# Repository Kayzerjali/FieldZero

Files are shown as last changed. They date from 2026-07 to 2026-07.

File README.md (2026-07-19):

# FieldZero — Magnetic Field Cancellation for OPM MEG

System to reduce the residual magnetic field inside the QUBIC lab's mu-metal shielded enclosure, allowing the QuSpin QZFM sensors to zero and lock reliably.

See `docs/context.md` for full project context.

## Status

In development — lab access pending.

## Repository layout

```
docs/                 Project documentation (grows as work progresses)
data/
  raw/                Unmodified instrument output (write-once)
  processed/          Script outputs only — never hand-edit
Hardware/             KiCad — coil-driver PCB (see Hardware/Low_Current_Driver/)
  Common/             Shared symbol/footprint libraries
Software/             Python acquisition/analysis tooling
  src/fieldzero/      Python package
  scripts/
    characterisation/ Field measurement and analysis
    coil_cal/         Coil sensitivity calibration
    nulling/          Nulling procedure support
    figures/          All figure generation
  tests/
```

The Python setup and commands below are run from inside `Software/`.

## Setup

Python 3.11+. A venv is created per machine — **do not copy `.venv` between
machines**, it hardcodes absolute paths and platform-specific wheels. Recreate it
instead; it takes about a minute.

```powershell
py -m venv .venv
.venv\Scripts\activate
pip install -e ".[daq,dev]"
```

`[daq]` pulls in `nidaqmx`. Drop it on a machine with no card — `--mock` needs
nothing else. Drop `dev` if you are not running the tests. The NI-DAQmx driver
itself is a separate install from National Instruments and is not a pip package.

### Installing on a machine with no internet

Instrument PCs are often locked down. Build a wheelhouse **before** you go, on a
machine that does have network:

```powershell
.venv\Scripts\python.exe -m pip download -d wheels numpy scipy fastapi "uvicorn[standard]" nidaqmx
```

Copy `wheels/` across with the repo, then on the lab machine:

```powershell
py -m venv .venv
.venv\Scripts\activate
pip install --no-index --find-links wheels -e ".[daq]"
```

The front end needs no network either — uPlot is vendored into
`src/fieldzero/viewer/static/vendor/` rather than loaded from a CDN.

## Live viewer

```bash
python -m fieldzero.viewer            # against the NI-DAQ
python -m fieldzero.viewer --mock     # no hardware required
```

Opens a browser at `http://127.0.0.1:8000`. Split any pane left/right or
top/bottom and choose what goes in it: time domain, frequency domain (amplitude
or ASD), or phase (any channel against any other, with Pearson r and fitted
slope). The stats table below the panes gives per-channel mean and standard
deviation, and flags any channel sitting at the input rail.

Layouts persist across reloads and can be saved to / loaded from JSON.

Run `scripts/characterisation/verify_acquisition.py [--mock]` on arrival at the
lab to confirm the DAQ is reading every channel before starting a measurement.

The viewer binds to loopback, so a Windows firewall prompt on first run can be
declined. Use `--host 0.0.0.0` to watch from a laptop while the DAQ machine sits
in the shielded room — that one does need the firewall exception.

## Fallback scope

A plain matplotlib window. No server, no browser, no socket — a timer reads the
ring buffer in-process, so there is nothing between acquisition and the screen
that can stall, congest or time out. Use it if the browser viewer feels sluggish
on a given machine, or when you just want a scope up in one command.

It runs the same reducers as the browser viewer, so the DSP is identical: the
same windowing, the same ASD scaling, the same volts-based rail check, the same
correlation maths. Only the drawing differs.

### Running it

```bash
python -m fieldzero.scope                # against the NI-DAQ
python -m fieldzero.scope --mock         # no hardware required
```

With no `--pane`, you get one time-domain plot of all six channels. Close the
window to stop it.

### Choosing what to plot

`--pane` takes `KIND` or `KIND:CH,CH,...` and is **repeatable** — each one adds a
plot, stacked top to bottom in the order you give them.

| kind | channels | shows |
|---|---|---|
| `time` | any number (default: all six) | rolling time trace, newest sample at t=0 |
| `spectrum` | any number (default: all six) | amplitude spectral density, log axis |
| `phase` | **exactly two** | first against second, with a least-squares fit |

Channel names are `S1-X`, `S1-Y`, `S1-Z`, `S2-X`, `S2-Y`, `S2-Z` — the same names
the stats table uses. Get one wrong and it tells you the valid ones and exits.

```bash
# one time plot of two channels, and their spectrum underneath
python -m fieldzero.scope --pane time:S1-X,S2-X --pane spectrum:S1-X,S2-X

# is sensor 2 seeing the same field as sensor 1?
python -m fieldzero.scope --pane phase:S1-X,S2-X

# what is the residual on the Z axis, in raw volts, over 10 seconds?
python -m fieldzero.scope --pane time:S1-Z,S2-Z --units V --window 10
```

### The other flags

| flag | default | what it does |
|---|---|---|
| `--mock` | off | simulated source; no DAQ needed |
| `--window N` | `5` | seconds of history each pane shows |
| `--units pT\|V` | `pT` | display units. **Volts are ground truth** — the V/nT figure is unverified |
| `--fps N` | `10` | redraw rate. Drop it to `5` on a slow machine |
| `--sample-rate N` | `1000` | samples/second per channel. Startup only |

### Reading the window

The red or grey strip along the top is the readout, updated twice a second:

- Normally it lists every channel's mean ± standard deviation in the chosen units.
- If **any channel is at the input rail** it turns red and says so, and it says
  nothing else. That warning takes priority because a clipped channel still
  reports a mean that looks like a perfectly reasonable field value. When you see
  it, the true field on that channel is larger than ±5 V can represent, and every
  number from it is fiction.

A phase pane also prints its Pearson *r* and fitted slope into that strip: *r*
near 1 means both channels are seeing the same field, and the slope is the gain
ratio between them.

### What you give up

Panes are fixed at launch. There is no clicking, no splitting, no changing
channels while it runs — to change the layout, close it and relaunch with
different `--pane` flags. That is the trade for having nothing that can go wrong.

### If you edit `scope.py`

Rendering uses blitting, and has to. A full matplotlib redraw of three panes
costs ~120 ms (~8 fps), and the cost is the redraw itself — thinning the data does
not help. Blitting the traces over a cached background costs ~20 ms instead. Two
consequences are load-bearing:

- **A pane's axes contain traces and nothing else.** Rasterising text costs more
  per frame than every trace in every pane put together (~27 ms vs ~22 ms), which
  is why all text lives in the status strip — it has its own bbox, so it can be
  redrawn at 2 Hz independently — and why legends and titles sit *above* the axes,
  outside the blitted region, where they survive in the cached background for free.
- **Axis limits use hysteresis.** They only move when the data leaves them, because
  a rescale forces a full redraw. Rescaling every frame would throw away
  everything blitting buys. `test_scope.py` asserts steady state needs none.

## Acquisition notes

Sample rate is a **startup** parameter (`--sample-rate`, default 1000 Hz), not a
runtime one: changing it means rebuilding the DAQ task, and doing that mid-run is
what made the previous project's axis switching unreliable. The task is opened
once over all six channels and never reconfigured; selecting an axis is purely a
display concern.

Acquisition yields **volts**. The V/nT conversion is applied at display time
(see below) — so saturation is detected against the known input range rather
than an unverified sensitivity figure.

## Hardware

| Item | Status |
|---|---|
| QuSpin QZFM sensors × 2 | In lab — gen TBD |
| Cancellation coils | Not yet installed |
| Current source | TBD |
| NI-DAQ (Dev1, ai0–ai5) | In lab — model TBD, confirm in NI MAX |

Three acquisition settings in `src/fieldzero/config.py` need confirming against
the actual card. MEG_DSP never set them, so it silently ran on the `nidaqmx`
defaults:

| Setting | Value | Why it matters |
|---|---|---|
| `voltage_range` | ±5 V | Where a channel clips. This is the `nidaqmx` default, never a decision. At the inherited 2.7 V/nT that is a clip at ~1.85 nT — and the residual field is believed to be nT-scale, so channels may already be railing. |
| `terminal_config` | RSE | RSE vs differential materially changes the noise floor. |
| `sensitivity_v_per_nT` | 2.7 | **Unverified** — inherited from MEG_DSP, and the QZFM generation is still unconfirmed. Volts are ground truth until this is checked against the sensor label. |

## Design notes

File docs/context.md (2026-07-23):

# FieldZero — Project Context

## The problem

The QUBIC MEG lab uses two QuSpin QZFM zero-field magnetometers inside a mu-metal shielded enclosure. The QuSpin has an internal field-zeroing loop but it has a limited capture range — it can only null the field if the residual field is already weak enough. The residual field inside the enclosure is strong enough that the internal zeroing either takes excessively long (~10 minutes) or fails entirely.

The lab previously spent time trying to fix this in software before realising the root cause was hardware: the residual field simply exceeds what the QuSpin internal coils can handle.

## The goal

Reduce the residual magnetic field inside the enclosure enough that the QuSpin internal zeroing acquires quickly and reliably. Once it locks, it handles the rest. This is a coarse acquisition problem, not a cancellation problem — the DC/quasi-static saturation-escape criterion is the core success bar.

**Architecture (scope shift from static trim)**: target moved from manual potentiometer set-and-forget to an active closed-loop PID cancellation system, per supervisor request. Not a one-time manual null.

**Success criterion**: both QuSpin sensors zero and lock in under ~2 minutes without intervention. This is not a strict requirement — it is a guide.

**Deliverable**: a system simple enough that any lab member can operate it following a procedure, without the original engineer present.

## Prior art

Holmes et al. 2023 (matrix coil active shielding for ambulatory MEG) is the direct predecessor: 48 unit coils on two planes, optical tracking for pose, spherical-harmonic projection (3 uniform + 5 gradient) via pseudo-inverse chained to a coil forward-model inverse, proportional feedback (Kp=0.4, 40 Hz, 25 ms latency), static shielding factor ~13.7×, moving ~5.2×. Their complexity (tracking + 48-coil inversion) solves a moving target over a whole-head volume — a problem we don't have with a small static 2-sensor enclosure. HFC (Tierney/Mellor) is the software-only version of the same harmonic projection; it's the lineage from the earlier 2-sensor common/differential PCA work → HFC → matrix coil.

## Field model and coil drive (worked through by hand, not yet bench-verified)

- Field over the region: B(r) = b₀ + G·(r−r₀) — uniform vector + gradient tensor. Needed because coils act over a region but we only measure at 2 points.
- Forward model y = H·b₀ (H from sensor geometry, not data), solved as b₀ = H⁺y. For two co-oriented triaxial sensors this collapses to: uniform = average of the two readings, gradient = difference / separation — the physics-derived version of the existing PCA common/differential split.
- **Observability limit**: 2 sensors separated along z can only observe ∂B/∂z (the z-column of G). Other gradient components are structurally invisible with this geometry.
- **Coil drive decomposition**: a biplanar pair has two natural modes — common mode (both coils same direction) → uniform field, differential mode (opposite) → gradient. This is a square, invertible 2×2 system: 2 observables (uniform Bz, ∂Bz/∂z), 2 knobs (common current, differential current). Physical currents I_T, I_B solved via M⁻¹ where M = [[p,q],[q,p]] (p,q = near/far coupling per amp, from Biot–Savart or bench).
- Currently z-axis only — a full uniform-vector cancellation needs 3 orthogonal coil pairs (Bx, By, Bz).

## Control architecture (settled)

The single-shot M⁻¹ solve applied every timeslice is itself a P-controller with Kp=1, but assumes a perfect forward model and static disturbance (both false — coil calibration is rough, field drifts). Fix: wrap the inversion in feedback — M⁻¹ gets close fast (feedforward), an integral term grinds to true zero (absorbs model error + drift). Practical form: PI, integral-dominant, one loop per drive mode (common-mode current, differential-mode current). D-term omitted — amplifies OPM noise, unnecessary for DC/quasi-static. Sign per axis must be verified on the bench (wrong sign → runaway).

Two nested loops in series: external coil loop = coarse acquisition into the QuSpin's ±few-nT capture range; QuSpin's internal null = fine trim. Bootstrapping: QuSpins are saturated on day 1, so the fluxgate does initial characterization until they come into range, then the OPMs become the loop sensor.

## Sensor data path (settled 2026-07-24)

How QZFM readings reach the coil driver. Each QZFM electronics module has **two independent outputs to the PC**: (1) **analog** — BNC per axis, ±5 V rail-to-rail, gain-selectable (2.7 V/nT default, 0.9 V/nT low, 8.1 V/nT high), read by the lab's NI DAQ (NI-9205, QuSpin's recommended unit); (2) **USB digital serial** — an FT232RL virtual COM port (115200 8N1) used by the QuSpin UI for calibration/zeroing/gain, which also streams 24-bit field values on the `Print ON` command (`(raw − 8388608) × 0.01 = pT`).

**Chosen path: PC-in-the-loop ("A1").** fields → NI-9205 (or QZFM USB serial) → PC (Python PID) → USB → Nano R4 → DAC8814 (SPI) → coils. The **MCU is a DAC bridge**, not the controller: it translates USB current commands to SPI DAC writes, holds the last-commanded current, and drops to safe-state (zero-current code) if the PC stops. Rationale: the loop is DC/quasi-static (<~few Hz), so the PC round-trip (~5–30 ms) is irrelevant — Holmes ran a harder moving-target loop at 40 Hz / 25 ms; **v010 already implements A1 with no board change**; and a PC is required in the room for the QuSpin UI regardless, so full MCU autonomy buys little (see [autonomous mode](#improvements--extensions-deferred) in Extensions).

**Ruled out: "NI DAQ → MCU directly."** An NI USB/cDAQ device is a USB peripheral requiring the NI-DAQmx driver stack on a host PC; the Nano R4 cannot host it. There is no DAQ→Arduino path.

**Capture-range caveat:** the QZFM analog output clips at ±1.85 nT (default gain) / ±5.5 nT (low gain), so the OPMs are only usable as the loop sensor once the field is already within range — the fluxgate must carry the bootstrap phase whichever routing is used.

## Electronics (settled)

Architecture: MCU → DAC → voltage-controlled current source (VCCS) per coil. Rejected DAC + series resistor (current = V/R_total drifts with coil copper temperature). VCCS uses a precision sense resistor inside the op-amp feedback loop so current is pinned at V_control/R_sense regardless of coil resistance.

Howland vs. series-sense is current-dependent, not a blanket call. Mrozowski et al. 2022 (Vernier Current Driver) show Howland current pumps degrade above ~50 mA — resistor self-heating unbalances the bridge, CMRR drops, and the drive stage's own heat couples into the control loop. Below that, their Howland-based LCD (DAC8814 + LTC6655 ref + OPA2210 pump) measures 14.6–15.1 ppb/√Hz, beating their series-sense HCD (16.5 ppb/√Hz at 250 mA). Our coil current for a ±10 nT trim field is expected well under 50 mA, so **adopting the LCD topology wholesale** (Howland pump, same op-amp/DAC/reference) rather than series-sense — revisit only if the coil transfer function (still unmeasured) demands more current than that.

Spec priority, in order:
1. Low current noise in-band — cheap to mitigate since the loop is <~few Hz, so filter hard / use a slow op-amp.
2. Short-term stability / low offset drift — use a chopper/auto-zero op-amp (offset appears as V_os/R_sense current error, kills it at DC).
3. Bipolar source-and-sink (currents go negative and flip sign — needs bipolar supply, no PWM/H-bridge switching noise).
4. Absolute accuracy matters least (feedback absorbs it).

R_sense: low-tempco foil/metal-film, sized so V_sense ≫ op-amp offset. DAC: ≥16-bit floor, resolution set by (total field span / capture range); possibly coarse+fine split.

## PCB (settled — as-built for first prototype, rev 0.1 / "v010")

The first prototype is board **rev 0.1** (schematic title-block `rev "0.1"`), referred to as **"v010"**; the next respin is **v011**. Working KiCad project: `Hardware/Low_Current_Driver/` — a duplicate of the Strathclyde Vernier LCD reference design, kept alongside its own copy of `Common/` since the lib tables use `${KIPRJMOD}/../Common/...` relative paths. The stray upstream clone under `docs/Vernier-Current-Driver/` is left untouched as reference — `Hardware/Low_Current_Driver/` is the only one that should be edited.

**Hierarchy (after the multichannel refactor):** root → `DAC` (→ `DAC_OPA` ×2, the A/B DAC buffers) · `MCU` · `Channel_Outputs` ×2 (`Coil_Drive_A`, `Coil_Drive_B`). The two coil drive channels are native KiCad multichannel instances of one `Channel_Outputs` sheet (z-axis common/differential — matches current single-axis scope). The reference design's `Power`, `Battery_Management`, and `Mounting_Holes` sheets were **removed** — see power entry below.

**Board specifics (settled, schematic-verified):**
- **MCU: Arduino Nano R4** (`A1`, replaces the reference design's ESP32-S3). The digital 5 V rail (`5VD`) is sourced from the Nano's own 5 V pin, not an on-board regulator. The ESP32-S3 symbol/footprint/STEP leftovers have been deleted and its `sym-lib-table` entry removed.
- **Power entry: external raw ±9 V through a 4-position Phoenix screw terminal** (`J3`, MKDS-1,5/4-5,08, MPN 1729144) carrying `+9V` / `−9V` / `GND` / `GNDA`, switched by a panel DPST switch (`SW1`, E-Switch RA83231100). The design source is **series 9 V batteries** (center-tapped for ground — the Vernier low-noise heritage; 9 V cells + snap leads are on the DigiKey list); a bench supply can substitute for characterization. **No on-board regulation or battery-management stage** — the reference design's ±12 V→±9 V LDOs (U4/U5/U6) and reverse-polarity front end are gone; raw ±9 V feeds the rails directly (down from the reference's ±12 V, adequate for the op-amp swing needed).
- **Coil connections: Molex Micro-Fit inline connectors** (`J1`, `J2`) — enamel coil wire spliced to a silicone-wire pigtail, crimped into a Micro-Fit, mated to a matching PCB-side connector.
- **Schematic ERC:** the two active drive channels (DAC A/B → buffers → coils) are clean. Two residual ERC errors remain on the DAC8814's **unused** C/D current outputs (`Iout_C`/`Iout_D` tied together and parked with a `PWR_FLAG`) — schematic-annotation only, no functional or copper impact; left as-is for the prototype.

**First-prototype scope cut (revisit before any lab-deployed build)**: the first board deliberately trades robustness for speed to get a characterization prototype on the bench. On-board power conditioning is omitted wholesale: no regulation (raw ±9 V comes straight from the battery pack), no reverse-polarity protection (MOSFET pair / polyfuses / TVS), no power-good LEDs or front-panel LED connector. A hard DPST switch (`SW1`) is the only power control — no soft on/off. Net effect: the board depends on a correctly-wired ±9 V source (battery pack or bench supply) and is unprotected against a reversed or over-voltage input. Acceptable for the bench-test/characterization build only; the project's own "operable by any lab member without the engineer present" deliverable goal implies regulation, protection, and idiot-proof power entry belong in whatever board actually ships to the lab.

## Protection — coil/op-amp side (settled by analysis)

Distinct from the reverse-polarity/idiot-proofing cuts above: the inductive-transient protection on the op-amp→coil side was analyzed on physics grounds and found genuinely unnecessary at this energy level — not a deadline compromise.

- **Stored coil energy is negligible.** E = ½LI² = ½(4 µH)(10 mA)² = **200 pJ** — seven orders of magnitude below a barely-perceptible ESD event.
- **SW1-off / brownout:** the coil sits in series with the sense resistor, so decay τ = L/R ≈ 4 µH / 1 kΩ ≈ 4 ns. The coil fully de-energizes ~a million times faster than the ±9 V rails can sag; the ~10 mA is far below any ESD-diode / latch-up threshold. **No op-amp output→rail clamp needed.**
- **Hot-unplug:** V_peak = I·√(L/C) into stray capacitance is only ~2–6 V — won't arc a connector and is trivially inside op-amp tolerance. A board-side clamp couldn't protect the coil anyway (it leaves on the far side of the break). **No coil-side TVS needed.**
- **Safe power-down is a firmware sequence, not hardware:** command all DAC channels to zero-current code (mid-scale for the bipolar output), assert `LDAC` so the op-amp ramps coil current to zero under closed-loop rail-bounded control, wait a few τ (ms is ample), *then* cut power. Coil energy is already zero before control is lost.
- **The one conditional item: MCU `D1` (VIN backfeed diode).** Only justified if the actual Nano R4 backfeeds its VIN pin when USB-powered with the ±9 V supply off. Decide by one measurement — power from USB only, bench supply off, read VIN: ~0 V → no protection diode needed at all; ~4–5 V → keep a series Schottky on VIN only. (The old `D2` 5 V-bridge diode was DNP — never populated, a no-op.)

## Fabrication — first prototype (settled 2026-07-23)

- **Board:** 4-layer, 127.75 × 53.0 mm, stackup F.Cu / GND / PWR / B.Cu. Ordered as a **bare PCB** (hand-assembled from the DigiKey BOM, not JLC PCBA).
- **Fab package:** `Hardware/Low_Current_Driver/fab1.zip` — gerbers + PTH/NPTH drills, regenerated 2026-07-23 08:16, byte-matches the current `.kicad_pcb`.
- **JLC quote:** $29.20 = $4.20 board + **$25 engineering (NRE) fee**, triggered by 4 layers **and** the >100 mm long edge (both push the order out of JLC's free-prototype tier). Not worth redesigning around — the GND/PWR planes are worth more than the fee.
- **DRC (KiCad 10.0.4, current board):** 0 errors, 0 unconnected, schematic parity clean; 1 cosmetic warning only (silk clipped by mask on an `HCP` test-point ref) — JLC auto-clips, non-blocking.
- **BOM / DigiKey:** MPN + DigiKey link live on each schematic symbol (no external BOM file); the curated purchase list is the DigiKey mylist **"FieldZero"** (7UCPWN2VGF), which also carries the 9 V batteries + snap leads (power source, not schematic symbols). All 15 schematic MPNs re-verified **Active** on DigiKey 2026-07-23, every one in stock except **J3 (Phoenix 1729144), Active-but-0-stock — deliberately off the order because the engineer has it at the UQ lab.** Parts ≈ $110/board at qty 1, dominated by DAC8814 $46.61, 4× OPA2210 $25.48, LTC6655 $14.63, Nano R4 $13.30.
- **Known metadata drift (harmless):** 100 nF caps carry Kemet `C0603C104K5RACTU` on the schematic vs Samsung `CL10B104KB8NNNC` on the PCB footprints — the orderable BOM exports from the schematic (Kemet). Test-point reference designators also differ between schematic (`TP15`…) and PCB (net-name labels). Neither affects the copper or the parts order.

## What is known

- Residual field estimated in the nT range
- Enclosure is mu-metal, sized to comfortably fit a styrofoam head with sensors mounted
- QuSpin software and NI-DAQ acquisition (Dev1, ai0–ai5, 2 sensors × 3 axes) already working from prior lab work
- The mu-metal provides passive attenuation but leaves a residual that exceeds the QuSpin capture range

## What is not yet known

- QuSpin gen — check hardware label when in lab (determines capture range and sensitivity spec)
- Exact residual field magnitude and which axes are worst — must be measured
- QuSpin internal capture range — need datasheet for confirmed gen
- Whether existing cancellation coils are installed or enclosure is bare
- Whether gradient control is needed at all: uniform-only cancellation leaves each sensor at ±(gradient×a); if that residual is below QuSpin capture range (~few nT), differential control can be skipped. Sensors are close together so uniform-only likely suffices, but the fluxgate campaign must measure the actual gradient across the baseline before deciding.
- Actual QZFM triaxial output and sensor separation vector — fixes H and the true loop count
- Coil geometry — determines whether the op-amp drives the coil directly (tens of mA, simple) or needs a pass transistor / power op-amp (amps, op-amp becomes the controller with R_sense staying in loop). Working estimate (≈4 µH inductance, ≤10 mA full-scale for a ±10 nT trim) sits firmly in the direct-drive regime, so no pass transistor is planned — provisional until the coil transfer function is bench-measured.

## Improvements / Extensions (deferred)

Forward-looking work that is understood but deliberately **not** in v010. Consolidated here so a v011 respin has a single checklist. Each item is traceable to a decision or measurement gap above.

- **Autonomous mode (no PC in the control loop).** The chosen path is PC-in-the-loop (see [Sensor data path](#sensor-data-path-settled-2026-07-24)); autonomous mode moves the PID onto the MCU and reads the QZFM analog outputs directly, so the box cancels with the PC out of the loop (NI DAQ demoted to logging/characterization). Requires a v011 respin: a **6-channel bipolar analog front-end** (±5 V QZFM outputs → attenuate + offset + anti-alias into ADC range) feeding a **dedicated SPI ADC** (≥16-bit, e.g. ADS1256-class) rather than the Nano R4's 14-bit unipolar onboard ADC. Justified only if a standalone (PC-free) controller is wanted — the QuSpin UI already needs a PC in the room, so this is a feature, not a requirement. The ±1.85/±5.5 nT analog clip still applies: the fluxgate carries bootstrap regardless.
- **Power conditioning + protection** (the first-prototype scope cut, above). For any lab-deployed board: on-board regulation (reference design's ±12→±9 LDOs or equivalent), reverse-polarity protection (MOSFET pair / polyfuses / TVS), power-good LEDs + front-panel LED connector, and ideally soft on/off replacing the hard DPST switch. v010 depends on a correctly-wired ±9 V source and is unprotected against reversal/over-voltage — bench-only. The "operable by any lab member" deliverable implies these belong on the shipped board.
- **Full 3-axis uniform cancellation.** v010 is z-axis only (2 channels: common/differential Bz). A full uniform-vector null needs 3 orthogonal coil pairs (Bx, By, Bz). The native multichannel sheet structure makes replicating the drive channel cheap; the DAC8814 is quad (2 channels used, 2 spare — one more axis fits before a second DAC is needed). Real constraints are board area and coil connectors.
- **Gradient control — decide, then possibly drop.** Whether differential (gradient) drive is needed at all depends on the measured gradient across the sensor baseline. If uniform-only cancellation leaves each sensor below QuSpin capture range, differential drive can be dropped, halving channels per axis. Blocked on the fluxgate gradient measurement (see What is not yet known).
- **Drop the NI DAQ from the loop.** Read fields straight off the QZFM USB serial (`Print ON`, 24-bit) if the stream rate suffices for a few-Hz loop, removing the NI-9205 from the control path: QZFM USB → PC → MCU USB. Keep the DAQ only for characterization/logging. Confirm the serial stream rate in the lab before committing.
- **Higher coil current (pass transistor / power op-amp).** Direct-drive (≤10 mA, Howland pump) assumes the ≈4 µH / ±10 nT working estimate holds. If the bench-measured coil transfer function needs >~50 mA, Howland degrades (sense-resistor self-heating unbalances the bridge) — switch to series-sense and/or add a pass transistor with R_sense kept in the loop.
- **DAC coarse+fine split.** If the required resolution (total field span / capture range) exceeds a single 16-bit DAC's usable range, split into summed coarse+fine DACs. Not needed at current working numbers; revisit after the field magnitude is measured.
- **MCU VIN backfeed diode (D1).** Conditional item from the protection analysis: only if the Nano R4 backfeeds VIN when USB-powered with ±9 V off. One measurement decides (VIN under USB-only power: ~0 V → no diode; ~4–5 V → series Schottky on VIN). Cheap to add on a respin.

## Resources
- A working example or capturing data from the qzfms can be seen in the repo
"https://github.com/Kayzerjali/MEG_DSP.git".
- Vernier Current Driver (Strathclyde EQOP, Mrozowski & Chalmers) — open-source ultra-low-noise bipolar current source, reference design for the coil-driver electronics and PCB: https://github.com/Strathclyde-EQOP/Vernier-Current-Driver — paper: https://arxiv.org/abs/2207.10348

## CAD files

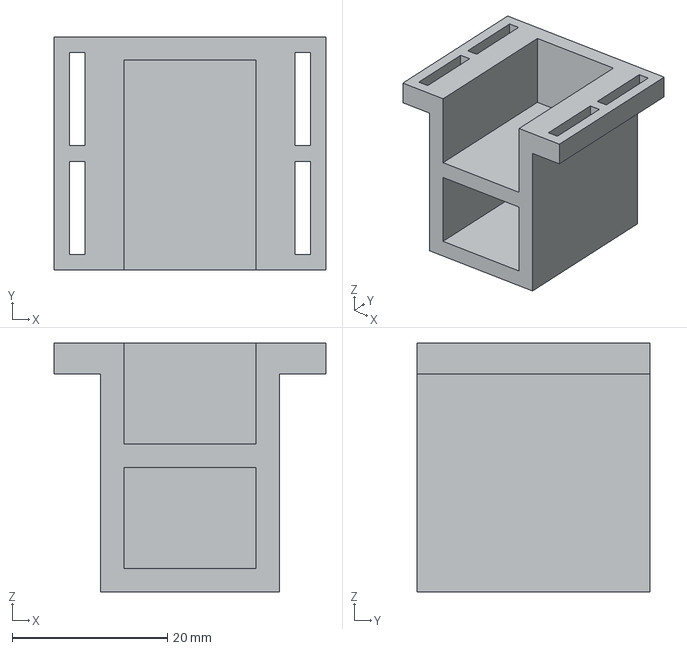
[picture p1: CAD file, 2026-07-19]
Hardware/cad/2sensor_holder_cap_hooks_pt.stp
35.0 x 30.0 x 32.0 mm

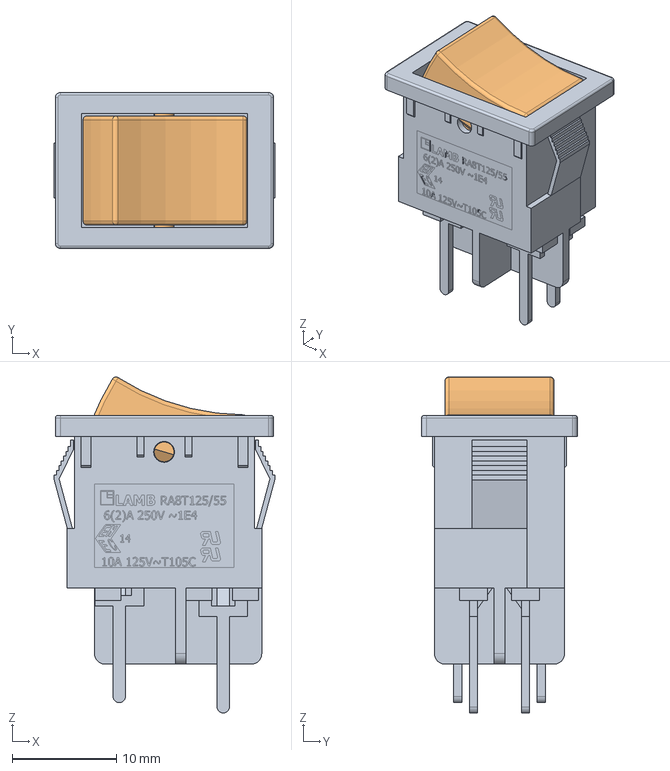
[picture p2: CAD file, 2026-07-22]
Hardware/Low_Current_Driver/3DModels/RA8323xx00 (1).stp
21.2 x 15.0 x 32.3 mm

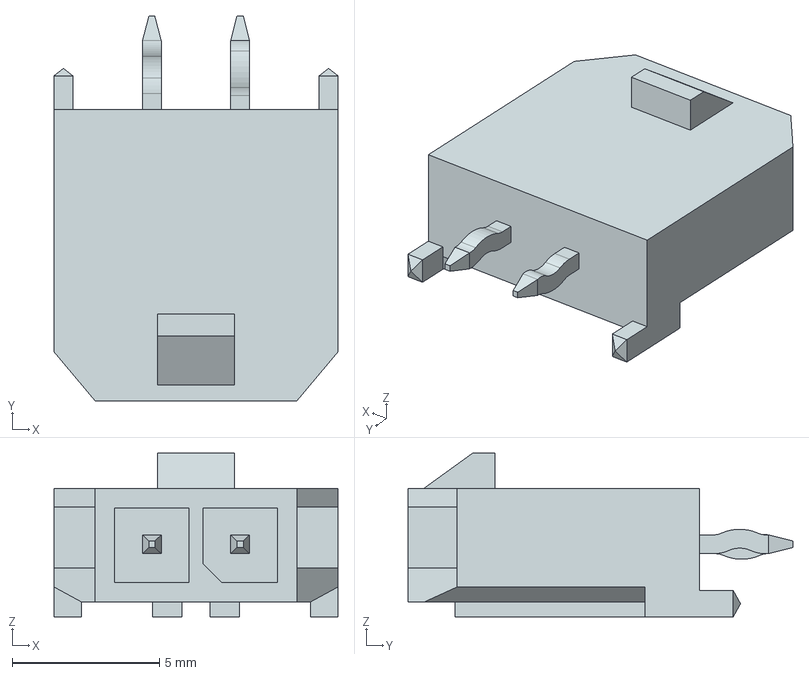
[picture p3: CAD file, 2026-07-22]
Hardware/Low_Current_Driver/3DModels/436500215.stp
9.65 x 13.1 x 5.57 mm

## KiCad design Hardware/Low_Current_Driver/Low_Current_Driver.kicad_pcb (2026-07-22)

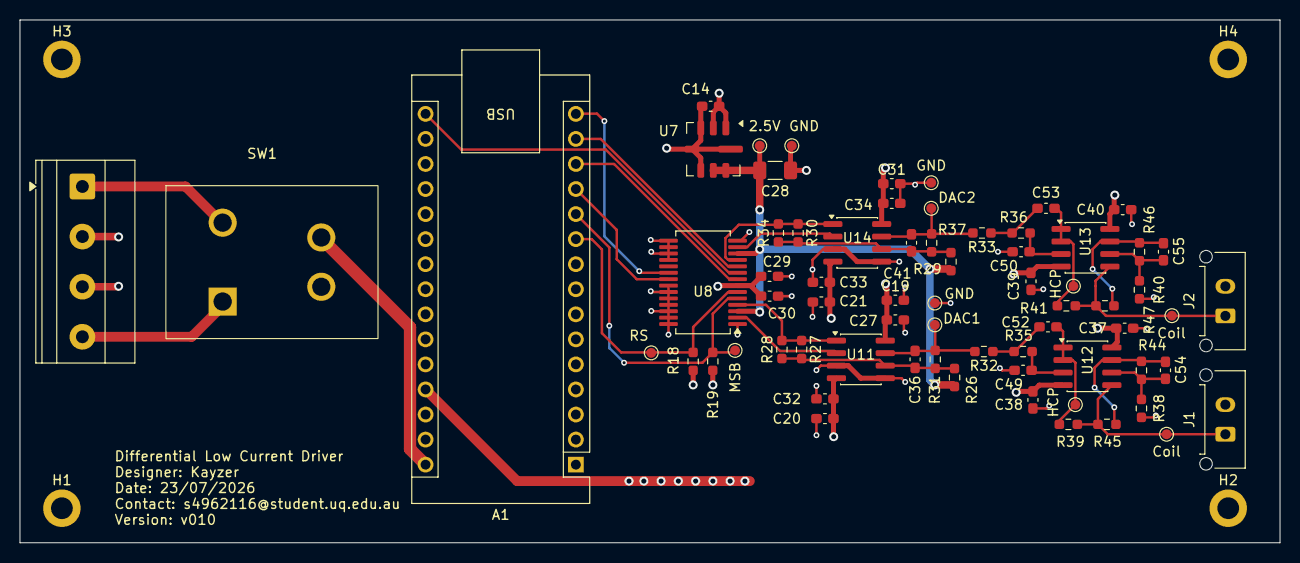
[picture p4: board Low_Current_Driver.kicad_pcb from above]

Board: 4 copper layers, 127.8 x 53.0 mm, 73 parts (0 on the bottom side), 34 nets.

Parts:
2.5V: TestPoint_Probe; TestPoint_Pad_D1.0mm
A1: Arduino_Nano_R4; Arduino_Nano
C14, C19, C20, C21, C30, C31, C36, C37, C38, C39, C40, C41: 100n; C_0603_1608Metric_Pad1.08x0.95mm_HandSolder
C27, C32, C33, C34, C49, C50, C52, C53: 1u; C_0603_1608Metric_Pad1.08x0.95mm_HandSolder
C28: 10u; C_1206_3216Metric_Pad1.33x1.80mm_HandSolder
C29: 10n; C_0603_1608Metric_Pad1.08x0.95mm_HandSolder
C54, C55: 4.7u; C_0603_1608Metric_Pad1.08x0.95mm_HandSolder
Coil: TestPoint_Probe; TestPoint_Pad_D1.0mm
Coil#2: TestPoint_Probe; TestPoint_Pad_D1.0mm
DAC1, DAC2: TestPoint_Probe; TestPoint_Pad_D1.0mm
GND: TestPoint_Probe; TestPoint_Pad_D1.0mm
GND#2, GND#3: TestPoint_Probe; TestPoint_Pad_D1.0mm
H1, H2, H3, H4: MountingHole_Pad; MountingHole_2.2mm_M2_DIN965_Pad
HCP: TestPoint_Probe; TestPoint_Pad_D1.0mm
HCP#2: TestPoint_Probe; TestPoint_Pad_D1.0mm
J1, J2: Conn_01x02_Socket; Molex_Micro-Fit_3.0_43650-0215_1x02_P3.00mm_Vertical
J3: Screw_Terminal_01x04; TerminalBlock_Phoenix_MKDS-1,5-4-5.08_1x04_P5.08mm_Horizont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
MSB: TestPoint_Probe; TestPoint_Pad_D1.0mm
R18, R19, R26, R27, R28, R29, R30, R31, R34, R37: 10k; R_0603_1608Metric_Pad0.98x0.95mm_HandSolder
R32, R33, R35, R36: 1k; R_0603_1608Metric_Pad0.98x0.95mm_HandSolder
R38, R39, R40, R41, R44, R45, R46, R47: 249; R_0603_1608Metric_Pad0.98x0.95mm_HandSolder
RS: TestPoint_Probe; TestPoint_Pad_D1.0mm
SW1: SW_DPST; DPST_RA83231100
U7: LTC6655-2.5; Analog_LCC-8_5x5mm_P1.27mm
U8: DAC8814; SSOP-28_5.3x10.2mm_P0.65mm
U11, U12, U13, U14: OPA2210; SOIC-8_3.9x4.9mm_P1.27mm

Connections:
+5VD: A1.27 (+5V), C14.1, C29.1, C30.1, R18.2, R19.2, U7.1 (~SHDN), U7.2 (Vin), U8.7 (VDD)
+9V: A1.30 (VIN), C19.1, C27.1, C31.1, C34.1, C37.1, C40.1, SW1.4, U11.8 (V+), U12.8 (V+), U13.8 (V+), U14.8 (V+)
-9V: C20.1, C21.1, C32.1, C33.1, C38.2, C39.2, SW1.2, U11.4 (V-), U12.4 (V-), U13.4 (V-), U14.4 (V-)
/Coil_Drive_A/HCP_FB: C54.2, R38.1, R44.2, U12.6 (-)
/Coil_Drive_A/HCP_Out: C54.1, R44.1, R45.1, U12.7
/Coil_Drive_A/Iin_coil: Coil.1 (1_1), J1.1, R39.1, R45.2, U12.5 (+)
/Coil_Drive_A/Vout_dac: C36.2, DAC1.1 (1_1), R31.2, R32.2, U11.7
/Coil_Drive_B/HCP_FB: C55.2, R40.1, R46.2, U13.6 (-)
/Coil_Drive_B/HCP_Out: C55.1, R46.1, R47.1, U13.7
/Coil_Drive_B/Iin_coil: Coil#2.1 (1_1), J2.1, R41.1, R47.2, U13.5 (+)
/Coil_Drive_B/Vout_dac: C41.2, DAC2.1 (1_1), R33.2, R37.2, U14.7
/DAC/CLK: A1.16 (SCK), U8.9 (CLK)
/DAC/DAC_Buffer_A/Iin: U8.2 (Iout_A), U11.2 (-)
/DAC/DAC_Buffer_A/Rfb: R27.1, R28.1, U8.4 (Rfb_A), U11.1
/DAC/DAC_Buffer_B/Iin: U8.13 (Iout_B), U14.2 (-)
/DAC/DAC_Buffer_B/Rfb: R30.1, R34.1, U8.11 (Rfb_B), U14.1
/DAC/MSB: A1.11 (D8), MSB.1 (1_1), R19.1, U8.5 (MSB)
/DAC/SDI: A1.14 (MOSI), U8.10 (SDI)
/DAC/SDO: A1.15 (MISO), U8.20 (SDO)
/DAC/Vref_2.5V: 2.5V.1 (1_1), C28.1, R26.1, R29.1, U7.6 (Vout_S), U7.7 (Vout_F), U8.3 (VREF_A), U8.12 (VREF_B)
/DAC/~CS: A1.13 (D10), U8.8 (~CS)
/DAC/~LDAC: A1.12 (D9), U8.21 (~LDAC)
/DAC/~RS: A1.10 (D7), R18.1, RS.1 (1_1), U8.6 (~RS)
GND: A1.4 (GND), A1.29 (GND), C14.2, C19.2, C20.2, C21.2, C27.2, C28.2, C29.2, C30.2, C31.2, C32.2, C33.2, C34.2, C37.2, C38.1, C39.1, C40.2, C49.2, C50.2, GND.1 (1_1), GND#2.1 (1_1), GND#3.1 (1_1), H1.1 (1_1), H2.1 (1_1), H3.1 (1_1), H4.1 (1_1), J1.2, J2.2, J3.2, J3.3, R38.2, R40.2, U7.3 (GND), U7.4 (GND), U7.5 (GND), U7.8 (GND), U8.1 (AGND_A), U8.14 (AGND_B), U8.15 (AGND_C), U8.16 (Iout_C), U8.17 (VREF_C), U8.18 (Rfb_C), U8.22 (AGND_F), U8.23 (VSS), U8.24 (DGND), U8.25 (Rfb_D), U8.26 (VREF_D), U8.27 (Iout_D), U8.28 (AGND_D), U11.3 (+), U11.5 (+), U14.3 (+), U14.5 (+)
unnamed: C52.2, R32.1, R35.2
unnamed: C53.2, R33.1, R36.2
unnamed: J3.1, SW1.3
unnamed: J3.4, SW1.1
unnamed: C36.1, R26.2, R27.2, R28.2, R31.1, U11.6 (-)
unnamed: C49.1, R35.1, U12.3 (+)
unnamed: C52.1, HCP.1 (1_1), R39.2, U12.1, U12.2 (-)
unnamed: C50.1, R36.1, U13.3 (+)
unnamed: C53.1, HCP#2.1 (1_1), R41.2, U13.1, U13.2 (-)
unnamed: C41.1, R29.2, R30.2, R34.2, R37.1, U14.6 (-)

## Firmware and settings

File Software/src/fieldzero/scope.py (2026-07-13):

"""
Lightweight matplotlib scope — the reliable fallback.

No server, no browser, no socket. A timer pulls straight from the ring buffer in
the same process, so there is nothing between acquisition and the screen that can
stall, congest or time out.

It reuses the same DataSource and the same reducers as the browser viewer, so the
DSP is identical — windowing, ASD scaling, the volts-based saturation check and
the correlation maths are all the tested code. Only the rendering differs. What
you give up is runtime reconfiguration: panes are chosen on the command line and
fixed for the session.

Rendering uses blitting, and it has to. A full matplotlib redraw of three panes
costs ~120 ms (~8 fps), and rewriting the titles each frame pushes it past 170 ms
— the redraw dominates completely, and no amount of thinning the data helps.
Blitting the traces over a cached background costs ~19 ms instead. So the static
furniture (axes, ticks, grid, labels) is drawn once, only the traces are redrawn,
and a full redraw happens solely when the axis limits genuinely need to move.

Usage:
    python -m fieldzero.scope --mock
    python -m fieldzero.scope --pane time:S1-X,S2-X --pane spectrum:S1-X
    python -m fieldzero.scope --pane phase:S1-X,S2-X --window 5
"""

from __future__ import annotations

import argparse
import sys
import time

import matplotlib.pyplot as plt
import numpy as np

from .config import AppConfig, ViewerConfig
from .datasource import DataSource, MockSignal, NIDAQ
from .reducers import PaneSpec, build, channel_stats

# Fewer points than the browser gets: on a plot a few hundred pixels wide there is
# nothing to see beyond this, and every point costs blit time.
SCOPE_POINTS = 500

# Rescale only when the data leaves the current limits, or rattles around in less
# than this fraction of them. Rescaling forces a full redraw, so doing it every
# frame would throw away everything blitting buys.
SHRINK_THRESHOLD = 0.5
GROW_MARGIN = 0.15

# Text is by far the most expensive thing to blit: rasterising the readout costs
# ~27 ms, against ~22 ms for every trace in every pane put together. So no text
# lives inside a pane's axes — the axes hold traces and nothing else — and the
# readout is a strip with its own bbox, blitted independently at this rate.
# Nobody reads numbers at 10 Hz anyway.
STATUS_HZ = 2.0

SERIES_COLORS = ["#1f77b4", "#2ca02c", "#ff7f0e", "#d62728", "#9467bd", "#17becf"]


class Pane:
    """One subplot, driven by one reducer. Owns only blittable artists."""

    def __init__(self, ax: plt.Axes, spec: PaneSpec, config: AppConfig):
        self.ax = ax
        self.spec = spec
        self.config = config
        self.viewer = ViewerConfig(decimation_points=SCOPE_POINTS,
                                   phase_points=SCOPE_POINTS)
        self.lines: list[plt.Line2D] = []
        self.fit_line: plt.Line2D | None = None
        self.legend = None
        self.readout = ""          # picked up by the status strip, not drawn here
        self._built = False

    @property
    def artists(self) -> list:
        """Traces only — deliberately no text. Everything else (legend, axis
        labels) sits in the cached background and is never redrawn."""
        out = list(self.lines)
        if self.fit_line is not None:
            out.append(self.fit_line)
        return out

    def _build(self, names: list[str], meta: dict) -> None:
        if self.spec.kind == "phase":
            (line,) = self.ax.plot([], [], linestyle="", marker=".", markersize=1.5,
                                   alpha=0.45, color=SERIES_COLORS[0])
            self.lines = [line]
            (self.fit_line,) = self.ax.plot([], [], color="#ff7f0e", linewidth=1.2)
        else:
            self.lines = [
                self.ax.plot([], [], linewidth=0.9, label=n,
                             color=SERIES_COLORS[i % len(SERIES_COLORS)])[0]
                for i, n in enumerate(names)
            ]
            if len(names) > 1:
                # Placed ABOVE the axes, deliberately. Blitting only restores
                # ax.bbox, so anything outside it is never overdrawn and can stay
                # baked into the cached background at zero cost per frame. A
                # legend inside the axes is painted through by the traces; and
                # re-blitting it each frame costs ~130 ms in text layout, which
                # is more than the entire rest of the redraw.
                # Right-aligned above the axes; the title takes the left, so the
                # two share the strip without colliding.
                self.legend = self.ax.legend(
                    loc="lower right", bbox_to_anchor=(1.0, 1.005), fontsize=7,
                    ncol=len(names), frameon=False, borderaxespad=0.0,
                    handlelength=1.4, columnspacing=1.4)
            if self.spec.kind == "spectrum":
                self.ax.set_yscale("log")

        # Titles sit above the axes, so they are outside ax.bbox and survive in the
        # cached background for free. They are set once and never change; anything
        # that varies (r, slope, means) goes to the status strip instead.
        if self.spec.kind == "spectrum":
            self.ax.set_title(
                f"{meta.get('mode', '')} — Δf {meta.get('resolution_hz', 0):.2f} Hz",
                fontsize=8, loc="left")
        elif self.spec.kind == "phase":
            self.ax.set_title(f"{names[0]} vs {names[1]}", fontsize=8, loc="left")

        self.ax.set_xlabel(meta.get("x_label", ""), fontsize=8)
        self.ax.set_ylabel(meta.get("y_label", ""), fontsize=8)
        self.ax.tick_params(labelsize=7)
        self.ax.grid(True, alpha=0.25, linewidth=0.5)
        self._built = True

    def _rescale_needed(self, lo: float, hi: float, cur: tuple[float, float]) -> bool:
        c0, c1 = cur
        if not np.isfinite([lo, hi, c0, c1]).all() or hi <= lo:
            return False
        if lo < c0 or hi > c1:
            return True
        return (hi - lo) < SHRINK_THRESHOLD * (c1 - c0)

    def update(self, snapshot) -> bool:
        """Refresh the traces. Returns True if the axis limits moved, meaning the
        caller must do a full redraw rather than a blit."""
        frame = build(self.spec, self.config.calibration, self.viewer).compute(snapshot)
        meta = frame.meta
        names = meta.get("series", [])

        x = frame.arrays.get("x")
        if x is None or x.size == 0:
            return False
        if not self._built:
            self._build(names, meta)
            return True                    # first draw must be a full one

        rescaled = False

        if self.spec.kind == "phase":
            y = frame.arrays["y"]
            self.lines[0].set_data(x, y)
            r, slope, icept = meta.get("r"), meta.get("slope"), meta.get("intercept")
            if slope is not None and x.size:
                edge = np.array([x.min(), x.max()])
                self.fit_line.set_data(edge, slope * edge + icept)
                self.readout = (f"{names[0]}/{names[1]}: r={r:+.4f} slope={slope:+.4f}")
            else:
                self.fit_line.set_data([], [])
                self.readout = f"{names[0]}/{names[1]}: r undefined (no variance)"
            for axis, data in (("x", x), ("y", y)):
                lo, hi = float(np.min(data)), float(np.max(data))
                cur = self.ax.get_xlim() if axis == "x" else self.ax.get_ylim()
                if self._rescale_needed(lo, hi, cur):
                    pad = max((hi - lo) * GROW_MARGIN, 1e-9)
                    setter = self.ax.set_xlim if axis == "x" else self.ax.set_ylim
                    setter(lo - pad, hi + pad)
                    rescaled = True
            return rescaled

        lo, hi = np.inf, -np.inf
        for line, name in zip(self.lines, names):
            y = frame.arrays[name]
            if self.spec.kind == "spectrum":
                # A log axis cannot draw a zero, and a railed channel's spectrum is
                # all zeros. Mask, so it cannot drag the scale down for everyone.
                y = np.where(y > 0, y, np.nan)
            line.set_data(x, y)
            if np.isfinite(y).any():
                lo = min(lo, float(np.nanmin(y)))
                hi = max(hi, float(np.nanmax(y)))

        self.ax.set_xlim(float(x[0]), float(x[-1]))

        if np.isfinite([lo, hi]).all() and hi > lo:
            if self.spec.kind == "spectrum":
                # Decades below the peak, snapped — same reasoning as the browser.
                top = 10 ** np.ceil(np.log10(hi))
                want = (top / 10**6, top)
                if not np.allclose(self.ax.get_ylim(), want, rtol=0.01):
                    self.ax.set_ylim(*want)
                    rescaled = True
            elif self._rescale_needed(lo, hi, self.ax.get_ylim()):
                pad = max((hi - lo) * GROW_MARGIN, 1e-9)
                self.ax.set_ylim(lo - pad, hi + pad)
                rescaled = True

        return rescaled


def parse_pane(text: str, config: AppConfig, window_s: float, units: str) -> PaneSpec:
    """`time:S1-X,S1-Y` -> a PaneSpec. Channels are optional for time/spectrum."""
    kind, _, chans = text.partition(":")
    kind = kind.strip().lower()
    if kind not in ("time", "spectrum", "phase"):
        raise argparse.ArgumentTypeError(
            f"pane kind must be time, spectrum or phase — got {kind!r}")

    known = [c.name for c in config.daq.channels]
    names = [c.strip() for c in chans.split(",") if c.strip()] or known
    for n in names:
        if n not in known:
            raise argparse.ArgumentTypeError(f"unknown channel {n!r}; known: {known}")
    if kind == "phase" and len(names) != 2:
        raise argparse.ArgumentTypeError(
            f"a phase pane needs exactly 2 channels, got {len(names)}")

    opts = {"mode": "asd"} if kind == "spectrum" else {}
    return PaneSpec(id=text, kind=kind, channels=tuple(names),
                    window_s=window_s, units=units, opts=opts)


class Scope:
    """Owns the figure and the blit loop."""

    def __init__(self, source: DataSource, config: AppConfig,
                 specs: list[PaneSpec], units: str, fps: float):
        self.source = source
        self.config = config
        self.units = units
        self.fps = fps

        rows = len(specs) + 1  # one thin strip at the top for the stats readout
        heights = [0.5] + [3.0] * len(specs)
        self.fig, axs = plt.subplots(
            rows, 1, figsize=(11, 1.0 + 2.6 * len(specs)), squeeze=False,
            gridspec_kw={"height_ratios": heights})
        self.fig.canvas.manager.set_window_title("FieldZero scope")

        self.status_ax = axs[0][0]
        self.status_ax.axis("off")
        self.status = self.status_ax.text(
            0.0, 0.5, "waiting for samples…", transform=self.status_ax.transAxes,
            va="center", fontsize=8, family="monospace")

        self.panes = [Pane(axs[i + 1][0], s, self.config) for i, s in enumerate(specs)]
        self.needed = int(round(max(s.window_s for s in specs) * config.daq.sample_rate))

        self._status_every = max(1, int(round(fps / STATUS_HZ)))
        self._ticks = 0

        self.fig.tight_layout()
        self._backgrounds: list = []
        # Recapture the cached backgrounds after ANY full redraw — our own, a
        # window resize, or a toolbar action. Without this a resize leaves the
        # blits painting onto a stale background.
        self.fig.canvas.mpl_connect("draw_event", self._capture)

    def _blit_axes(self) -> list[plt.Axes]:
        return [self.status_ax] + [p.ax for p in self.panes]

    def _capture(self, _event=None) -> None:
        self._backgrounds = [self.fig.canvas.copy_from_bbox(ax.bbox)
                             for ax in self._blit_axes()]

    def _status_text(self, snapshot) -> tuple[str, str]:
        stats = channel_stats(snapshot, self.config.calibration, self.units,
                              self.config.daq.voltage_range)
        railed = [s["name"] for s in stats if s["saturated"]]
        extra = "   ".join(p.readout for p in self.panes if p.readout)

        if railed:
            # A clipped channel still reports a plausible-looking mean. This
            # warning is the one thing that must never be missed.
            return (f"AT THE INPUT RAIL: {', '.join(railed)}  -  their {self.units} "
                    f"values are meaningless", "#d62728")
        body = "  ".join(f"{s['name']} {s['mean']:+8.1f}+-{s['std']:.1f}" for s in stats)
        return f"{self.units}: {body}    {extra}", "#333333"

    def tick(self) -> None:
        snapshot = self.source.get_data(self.needed)
        if snapshot.n_samples == 0:
            return

        full = False
        for pane in self.panes:
            full |= pane.update(snapshot)

        self._ticks += 1
        due = self._ticks % self._status_every == 0

        if full or not self._backgrounds:
            # Limits moved, so the cached background (ticks, gridlines) is stale.
            # Pay for one full redraw; _capture refreshes the cache via draw_event.
            text, color = self._status_text(snapshot)
            self.status.set_text(text)
            self.status.set_color(color)
            self.fig.canvas.draw_idle()
            return

        canvas = self.fig.canvas

        # The traces: every tick, and cheap, because the axes hold nothing else.
        for pane, bg in zip(self.panes, self._backgrounds[1:]):
            canvas.restore_region(bg)
            for artist in pane.artists:
                pane.ax.draw_artist(artist)
            canvas.blit(pane.ax.bbox)

        # The readout: its own bbox, so it can be left alone on the ticks where we
        # skip it. Untouched pixels simply persist from the last blit.
        if due:
            text, color = self._status_text(snapshot)
            self.status.set_text(text)
            self.status.set_color(color)
            canvas.restore_region(self._backgrounds[0])
            self.status_ax.draw_artist(self.status)
            canvas.blit(self.status_ax.bbox)

        canvas.flush_events()

    def _on_timer(self) -> None:
        # matplotlib's Tk timer re-arms with after(interval) only once the callback
        # has returned, so the real period is interval + work, not interval — at
        # 10 fps with 55 ms of drawing that yields about 6 fps. Tick faster than
        # the target and gate on elapsed time instead, so the requested rate is
        # actually met whenever the work fits inside it.
        now = time.perf_counter()
        if now - self._last_render < 1.0 / self.fps:
            return
        self._last_render = now
        self.tick()

    def run(self) -> None:
        self._last_render = 0.0
        timer = self.fig.canvas.new_timer(interval=max(5, int(250.0 / self.fps)))
        timer.add_callback(self._on_timer)
        timer.start()
        plt.show()


def main(argv: list[str] | None = None) -> int:
    parser = argparse.ArgumentParser(
        prog="fieldzero.scope",
        description="Lightweight matplotlib scope (fallback for the browser viewer)")
    parser.add_argument("--mock", action="store_true", help="no DAQ hardware required")
    parser.add_argument("--pane", action="append", default=None, metavar="KIND[:CH,CH]",
                        help="repeatable, e.g. time:S1-X,S2-X | spectrum:S1-Z | phase:S1-X,S2-X")
    parser.add_argument("--window", type=float, default=5.0, help="seconds of history (default 5)")
    parser.add_argument("--units", choices=["pT", "V"], default="pT")
    parser.add_argument("--fps", type=float, default=10.0, help="redraw rate (default 10)")
    parser.add_argument("--sample-rate", type=float, default=None)
    args = parser.parse_args(argv)

    config = AppConfig()
    if args.sample_rate is not None:
        config = config.with_sample_rate(args.sample_rate)

    try:
        specs = [parse_pane(p, config, args.window, args.units)
                 for p in (args.pane or ["time"])]
    except argparse.ArgumentTypeError as exc:
        parser.error(str(exc))

    source: DataSource
    if args.mock:
        source = MockSignal(config.daq)
        source.start()
    else:
        try:
            source = NIDAQ(config.daq)
        except Exception as exc:
            print(f"Could not open the NI-DAQ: {exc}", file=sys.stderr)
            print("Run with --mock to use the simulated source.", file=sys.stderr)
            return 1

    vmin, vmax = config.daq.voltage_range
    print(f"FieldZero scope — source={type(source).__name__} "
          f"fs={config.daq.sample_rate:g} Hz  range={vmin:+g}..{vmax:+g} V  "
          f"panes={len(specs)}")
    print("Close the window to stop.")

    try:
        Scope(source, config, specs, args.units, args.fps).run()
    except KeyboardInterrupt:
        pass
    finally:
        source.close()
    return 0


if __name__ == "__main__":
    raise SystemExit(main())

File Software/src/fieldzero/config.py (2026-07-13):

"""
Configuration for FieldZero acquisition and display.

Everything an operator may need to change lives here. The channel map is the
single source of truth for channel identity: the DAQ builds its task from it and
the viewer builds its channel selector from it, so the two cannot drift apart.
"""

from dataclasses import dataclass, field, replace


@dataclass(frozen=True)
class Channel:
    """One analog input: its physical DAQ terminal and what it measures."""

    name: str           # short label shown in the UI, e.g. "S1-Z"
    device_channel: str  # NI terminal, e.g. "Dev1/ai2"
    sensor: int         # which QuSpin (1 or 2)
    axis: str           # "x" | "y" | "z"


# Channel map inherited from MEG_DSP: Dev1/ai0-ai5 = 2 sensors x 3 axes.
# Adding a third sensor means appending three entries here and nothing else.
CHANNEL_MAP: tuple[Channel, ...] = (
    Channel("S1-X", "Dev1/ai0", 1, "x"),
    Channel("S1-Y", "Dev1/ai1", 1, "y"),
    Channel("S1-Z", "Dev1/ai2", 1, "z"),
    Channel("S2-X", "Dev1/ai3", 2, "x"),
    Channel("S2-Y", "Dev1/ai4", 2, "y"),
    Channel("S2-Z", "Dev1/ai5", 2, "z"),
)


@dataclass(frozen=True)
class DaqConfig:
    """
    NI-DAQ acquisition parameters.

    voltage_range and terminal_config were never set explicitly in MEG_DSP, so
    that acquisition silently ran on nidaqmx's defaults (min_val=-5.0,
    max_val=5.0, TerminalConfiguration.DEFAULT). They are stated here because
    both matter: the range sets where a channel clips, and RSE vs differential
    changes the noise floor. Confirm against the card in NI MAX.
    """

    channels: tuple[Channel, ...] = CHANNEL_MAP
    sample_rate: float = 1000.0
    voltage_range: tuple[float, float] = (-5.0, 5.0)
    terminal_config: str = "RSE"  # "RSE" | "NRSE" | "DIFF" | "DEFAULT"
    buffer_seconds: float = 60.0  # ring buffer depth; bounds the longest window
    read_chunk: int = 100         # samples per DAQ read in the acquisition thread

    @property
    def n_channels(self) -> int:
        return len(self.channels)


@dataclass(frozen=True)
class Calibration:
    """
    Volts -> field conversion.

    Acquisition always yields volts; this is applied at display time. The
    2.7 V/nT figure is inherited from MEG_DSP and is NOT verified against a
    datasheet — the QZFM generation in the lab is still unconfirmed. Until it
    is, treat volts as ground truth and pT as indicative.
    """

    sensitivity_v_per_nT: float = 2.7
    saturation_fraction: float = 0.98  # fraction of the rail that counts as clipped

    def volts_to_pT(self, volts):
        return (volts / self.sensitivity_v_per_nT) * 1000.0

    def scale(self, units: str) -> float:
        """Multiplier taking volts into `units`."""
        if units == "V":
            return 1.0
        if units == "pT":
            return 1000.0 / self.sensitivity_v_per_nT
        raise ValueError(f"unknown units {units!r} (expected 'V' or 'pT')")


@dataclass(frozen=True)
class ViewerConfig:
    """Display-side parameters. None of these touch the hardware."""

    refresh_hz: float = 20.0
    decimation_points: int = 2000  # target points per trace after min/max decimation
    default_window_s: float = 10.0
    phase_points: int = 2000       # points in a phase-plot cloud
    host: str = "127.0.0.1"
    port: int = 8000


@dataclass(frozen=True)
class AppConfig:
    daq: DaqConfig = field(default_factory=DaqConfig)
    calibration: Calibration = field(default_factory=Calibration)
    viewer: ViewerConfig = field(default_factory=ViewerConfig)

    def with_sample_rate(self, rate: float) -> "AppConfig":
        return replace(self, daq=replace(self.daq, sample_rate=rate))

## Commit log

2026-06-28 Slim CLAUDE.md to working style only
    Project context lives in docs/context.md. CLAUDE.md now only describes
    how to collaborate — no duplicated content.
2026-07-13 Add live viewer, matplotlib scope, and decoupled acquisition
    Acquisition
    - Open the NI-DAQ task once over all six channels and never reconfigure it.
    MEG_DSP rebuilt the task inside set_axis() while acquisition was live, which
    tore down timing and buffers underneath a reader already blocked in read().
    Axis selection is now purely a display concern.
    - get_data() reads a ring buffer fed by a dedicated acquisition thread, so it
    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
2026-07-19 Reorganize into Hardware/ and Software/; add coil-driver KiCad project
    Split the repo along the hardware/software boundary now that the coil
    driver is a PCB effort. The Python acquisition/analysis tooling (src,
    scripts, tests, setup.py) moves wholesale under Software/ unchanged; the
    Low_Current_Driver KiCad project and shared Common/ libraries land under
    Hardware/.
    Ignore KiCad session/lock/backup cruft, the VS Code .history/ store,
    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
    [2sensor_holder_cap_hooks_pt.stp, Battery_Management.kicad_sch, Battery_Management.sch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]
2026-07-19 docs: record PCB-stage decisions (Nano R4, ±9V rails, coil/protection)
    Capture what settled in the schematic phase before routing begins:
    - MCU is the Arduino Nano R4, not the reference design's ESP32-S3; 5VD
    sourced from the Nano's 5V pin.
    - Analog rails set to ±9V (down from ±12V), schematic-verified.
    - Coil connections via Molex Micro-Fit inline connectors.
    - Coil estimate (~4uH, <=10mA) confirms direct op-amp drive, no pass
    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
2026-07-20 Checkpoint before channel-replication refactor
    Snapshot of schematic/PCB work-in-progress prior to restructuring
    Channel_Outputs into a reusable hierarchical channel sheet for
    replicate-layout. Adds DPST relay footprint.
    [Channel_Outputs.kicad_sch, DAC.kicad_sch, Low_Current_Driver.kicad_pcb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]
2026-07-22 Replicate coil drive channel via native multichannel sheets
    Root schematic now instantiates Channel_Outputs.kicad_sch twice as
    Coil_Drive_A / Coil_Drive_B, with DAC_OPA.kicad_sch added as a sub-sheet
    of DAC.kicad_sch (also instantiated twice). PCB relaid out to match.
    Also drops the abandoned ESP32-S3 leftovers (footprint file and the
    sym-lib-table entry pointing at an absolute path), removes the stale
    Low_Current_Driver-cache legacy lib entry, and adds the STEP models
    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
    [436500215.stp, Battery_Management.kicad_sch, Channel_Outputs.kicad_sch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]
2026-07-22 Add fab1 package and update docs to as-built for first prototype
    - Add fab1.zip + gerbers/drills (4-layer, 127.75x53mm) for JLC bare-board order
    - Rewrite context.md PCB section to as-built: external raw ±9V via J3→SW1,
    no on-board LDOs/battery-mgmt; record removed Power/Battery_Management/
    Mounting_Holes sheets and honest ERC state (2 residual errors on DAC8814
    unused C/D outputs, benign)
    - Add "Fabrication — first prototype" section: board stack, $25 JLC NRE fee,
    DRC clean, DigiKey BOM verified Active 2026-07-23
    - Finalize channel-replication refactor edits (DAC/DAC_OPA/Channel_Outputs)
    - Remove stale DRC violations report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
    [Battery_Management.kicad_sch, Channel_Outputs.kicad_sch, DAC.kicad_sch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]
2026-07-23 docs: add sensor data path decision and Extensions section for v011
    - Record QZFM two-output interface (analog->NI-9205, USB serial +
    Print ON stream) and the chosen PC-in-the-loop (A1) path: MCU as
    DAC bridge, PID on PC; rule out "NI DAQ -> MCU directly"
    - Add consolidated Improvements/Extensions (deferred) v011 checklist,
    led by autonomous mode (6-ch bipolar analog front-end + SPI ADC)
    - Anchor version scheme (rev 0.1 / "v010", next = v011)
    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
